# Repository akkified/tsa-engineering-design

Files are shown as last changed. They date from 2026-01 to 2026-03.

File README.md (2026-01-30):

# AI Powered Robotic Arm Lab Assistant

## What It Is

Our team proposes a low-cost, highly accessible lab robotic arm intended for use by students, educators, and small scale labs around the world. This design addresses the lack of access to advanced laboratory automation technologies in underfunded educational and research environments. By implementing additive manufacturing through 3D printing, open source electronics, and wide range mobility, the platform serves as a flexible, modular, and easily accessible laboratory assistant suitable for both instructional and research applications. <br><br>
Because the arm is primarily created using 3D printed components, the overall cost is reduced by approximately 90% compared to a commercially available lab assistant robot. This substantial cost reduction allows for schools, communities, and institutions to create multiple units, therefore increasing accessibility and supporting hands on, scalable learning experiences.<br><br>
All mechanical designs, electronic schematics, and software components have been released as open source materials. Users can independently manufacture the arm, replace individual components as needed, and modify the design files as per their own needs. This open framework also supports a collaborative ecosystem for shared enhancements, including the addition of new grippers, sensors, tools, and automation scripts, allowing for continuous improvements to the design. <br><br>
The robotic arm was designed with a strong emphasis on its mechanical simplicity, flexibility, and ease of construction. A 7 degree of freedom (DOF) configuration was used to create a range of motion beyond that of a human arm, allowing the system to reach complex orientations. All of the components were modeled using computer aided design (CAD), allowing for precision, control over joint geometry, and tolerances. Cycloidal drive mechanisms are implemented into the assemblies to provide high torque and smooth motion while mitigating or significantly reducing backlash, improving the overall positioning accuracy during laboratory tasks. The design of the end effector allows users to replace individual components, attach custom tools, and even integrate new sensors without having to redesign the entire system.<br><br>
	The robotic arm uses an integrated Controller Area Network (CANBUS) communication system to simplify the signal processing and reduce the amount of internal cabling required. In addition to its communication architecture, the system incorporates computer vision using a YOLOv11-based object detection model. Overall, these features improve system efficiency while supporting scalable and adaptable laboratory automation.<br>

## Why We Made This

   We designed this robotic arm to fill a major gap that we observed in educational and laboratory environments. Most advanced tools that assist with automating procedures are extremely expensive and proprietary, which makes  them inaccessible to students and researchers who work in small scale labs who need the most help from this technology. Though the industrial level robotic arms are relatively common in well funded labs and non-educational environments, their high cost and closed ecosystems make the technology significantly less viable to classrooms that could possibly use this as an educational tool, community labs, and underfunded research labs. <br><br>
   In many labs, repetitive tasks like pipetting, sample transfers, positioning instruments, and handling hazardous materials are done manually by the researchers. This seriously limits the possible efficiency of the lab and increases the likelihood of fatigue, human error, and safety hazards. The current industry systems that could automate these tasks cost tens of thousands of dollars and need hgihly specialized maintenance because of their closed off design, which makes them very unrealistic for small scale labs and most schools. <br><br>
   Our main goal with this design was to create a robotic arm that will help significantly reduce the entry barrier to this technology while still remaining functional and precise. By prioritizing the ability to 3D print the majority of the components, open source electronics, and the modular design, we were able to reduce the cost by almost 90% while still creating a highly capable robotic assistant. This arm can be scaled up into a system of communicating assistive devices that can work together. The reduced cost also makes it possible for a high level lab to deploy several of these arms in comparison to a single high cost version. This system will help schools with low funding and small labs create a much more hands on learning environment, run parallel experiments, and scale their automation of tasks. <br><br>
   We chose to make this project fully open source with minimal protections (Reference MIT Licence, txt and CERN Open Hardware Licence Version - Permissive.txt) because we believe that the development  and usage of this technology should not be limited by proprietary constraints like the majority of mainstream robotics technologies. By releasing all of the CAD files, schematics, and software that we have, we hope that the users of this repository will understand the system itself, repair it on their own, and adapt or even improve on our work. We hope that this approach will encourage learning robotics through doing and designing independently. We would love for the global community on GitHub to improve the design over time by creating new end effectors, tools, control strategies, and AI implementations. <br><br>
   Overall, this robotic arm was designed to spread lab automation. It was created to not just be a tool for innovation but also a platform for developing independent work. We hope that our contribution and efforts here will support education, research, and lab automation by making advanced robotic technologies significantly more affordable and customizable to anyone in the community willing to learn and build this technology further.<br>

## CAD Viewer

<script type="module" src="https://unpkg.com/@google/model-viewer/dist/model- viewer.min.js"></script>

<!-- <model-viewer 
  src="https://akkified.github.io/tsa-engineering-design/cad/model.glb" 
  alt="Interactive CAD model" 
  auto-rotate 
  camera-controls 
  ar 
  style="width: 100%; height: 400px;">
</model-viewer> -->

## Images

### 3D CAD Model
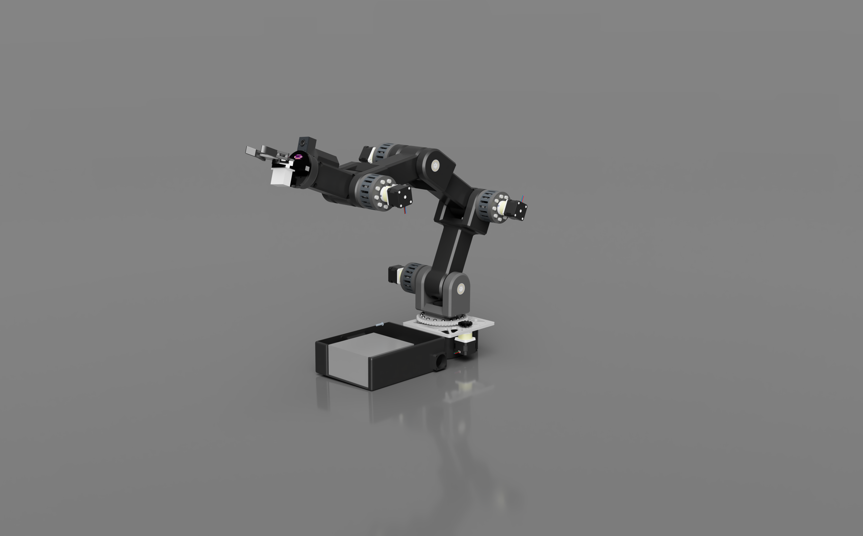
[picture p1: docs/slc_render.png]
Render

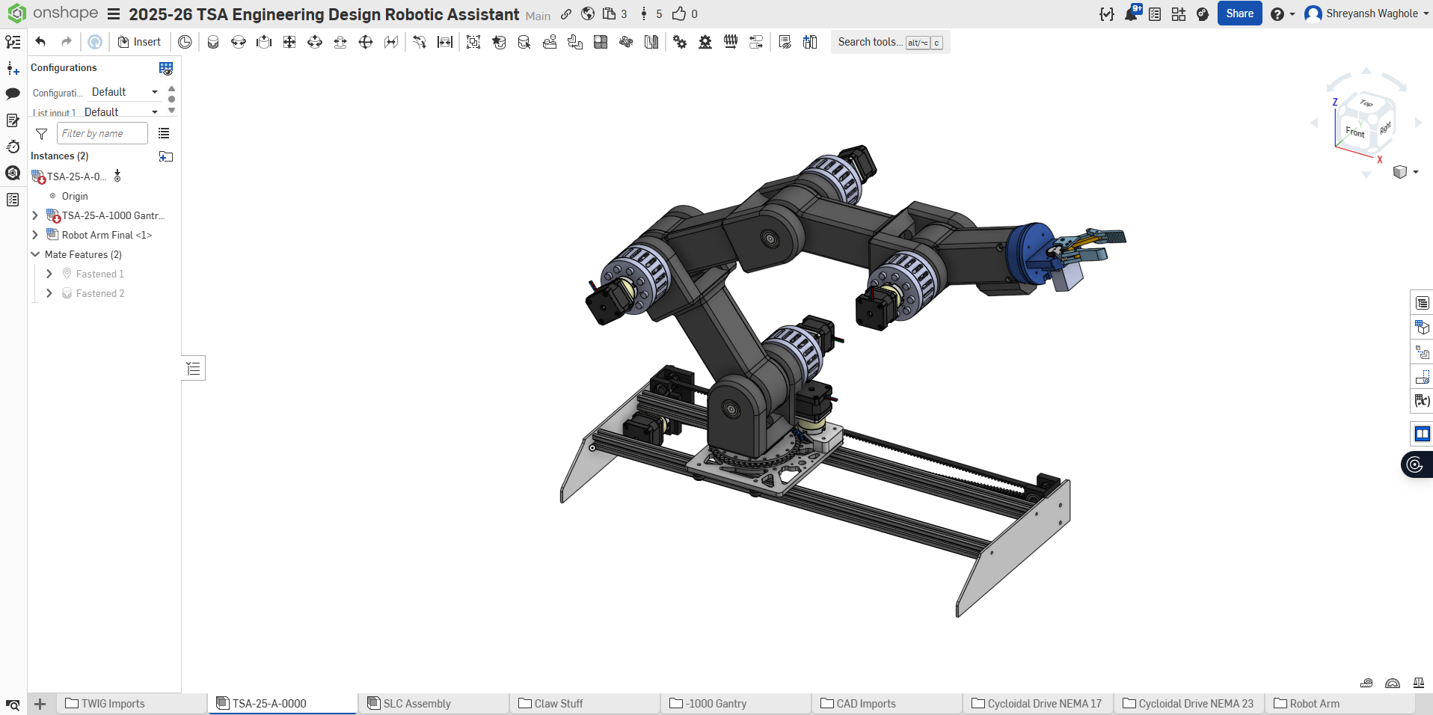
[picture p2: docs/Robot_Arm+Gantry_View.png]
Robot Arm Gantry View

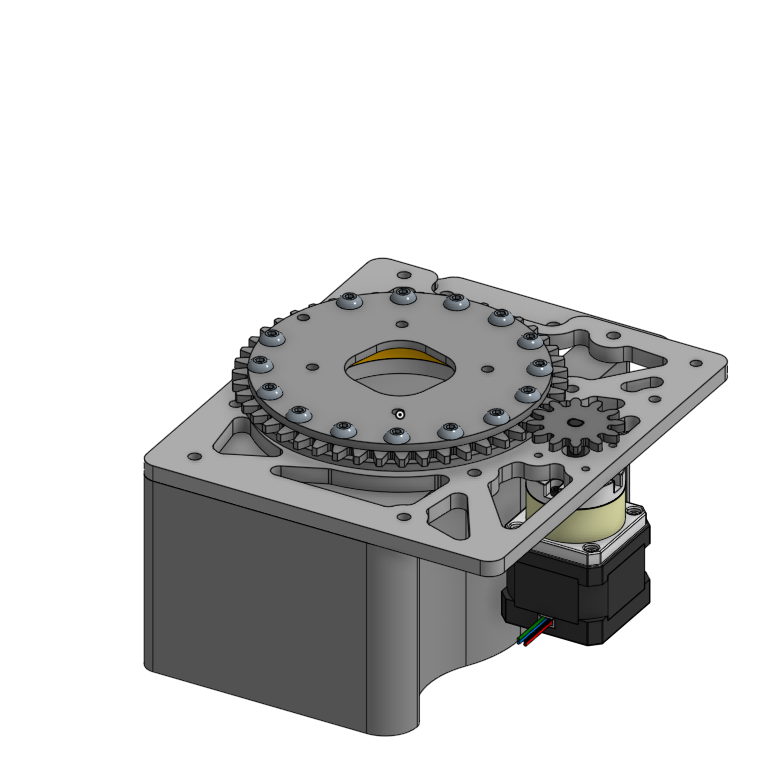
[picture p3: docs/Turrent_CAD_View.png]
Turret CAD View

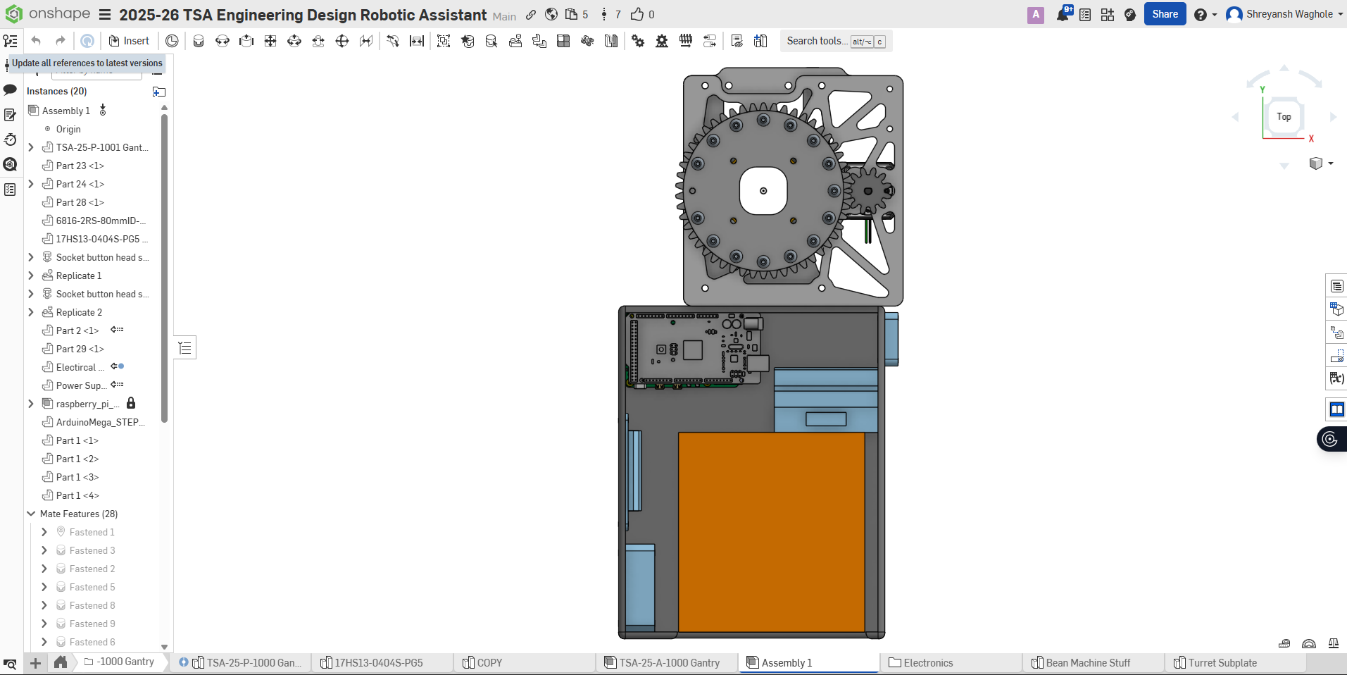
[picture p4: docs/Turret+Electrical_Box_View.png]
Turret Electrical Box View


### Wiring Diagram
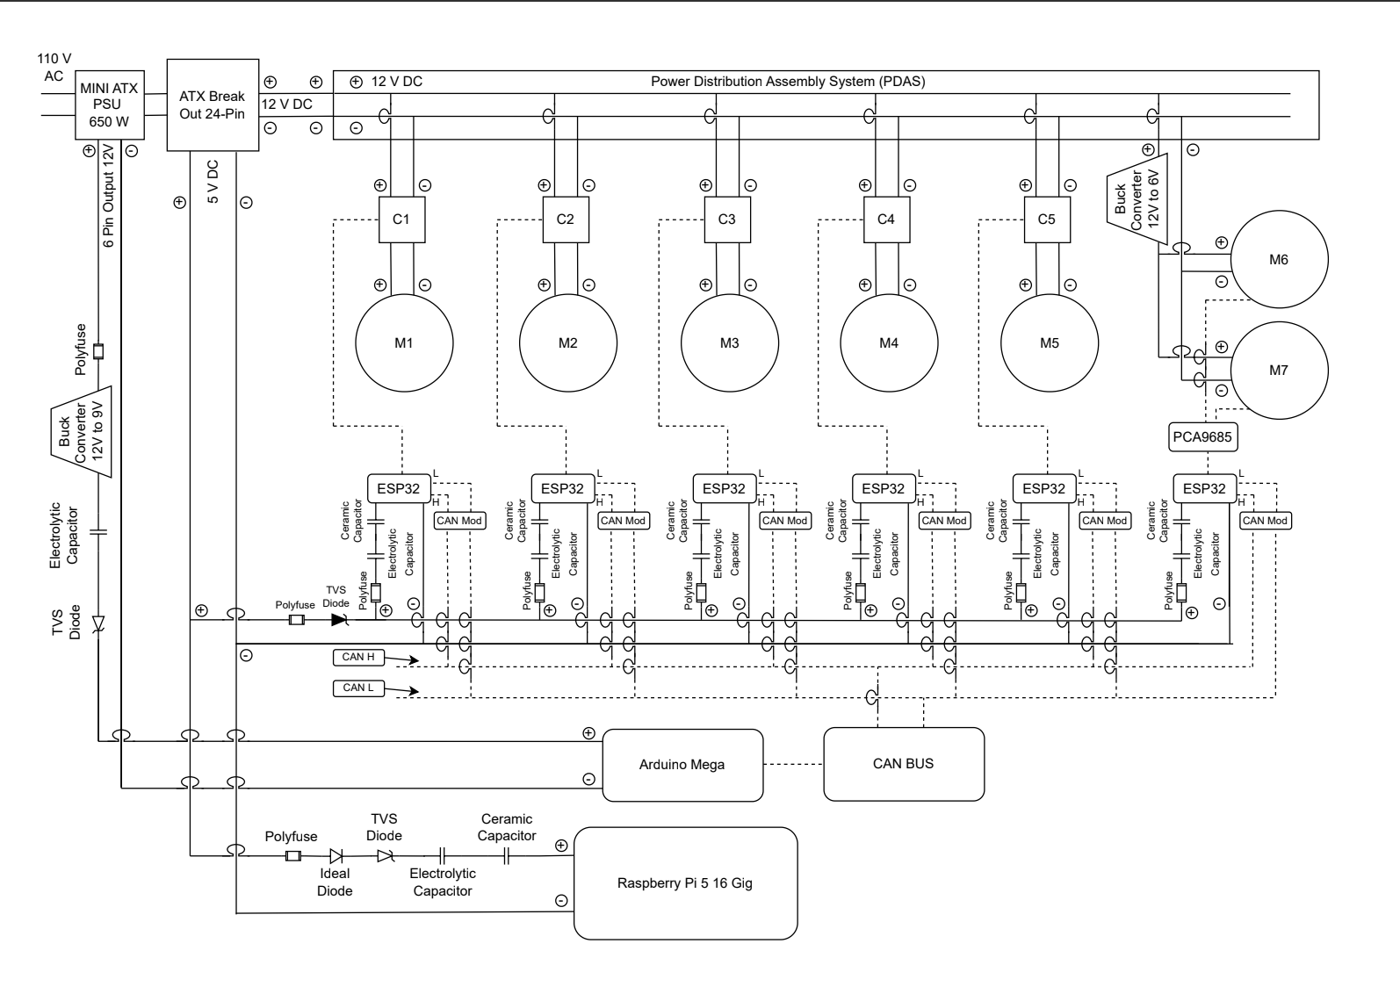
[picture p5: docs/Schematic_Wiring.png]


### AI Performance (Vision)
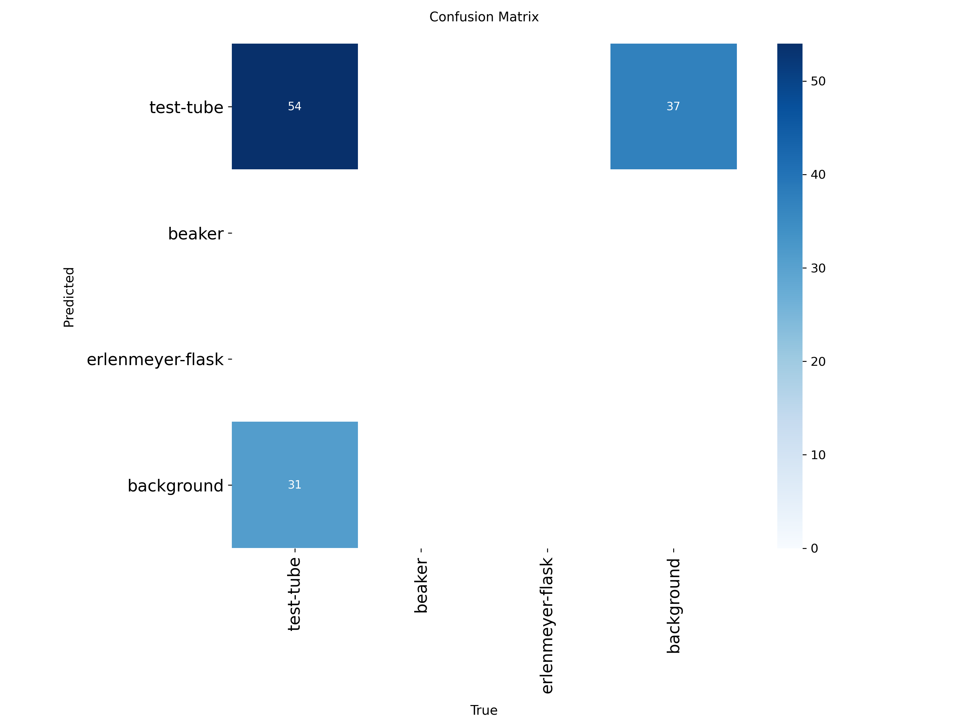
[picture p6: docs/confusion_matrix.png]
Confusion Matrix


### Cycloidal
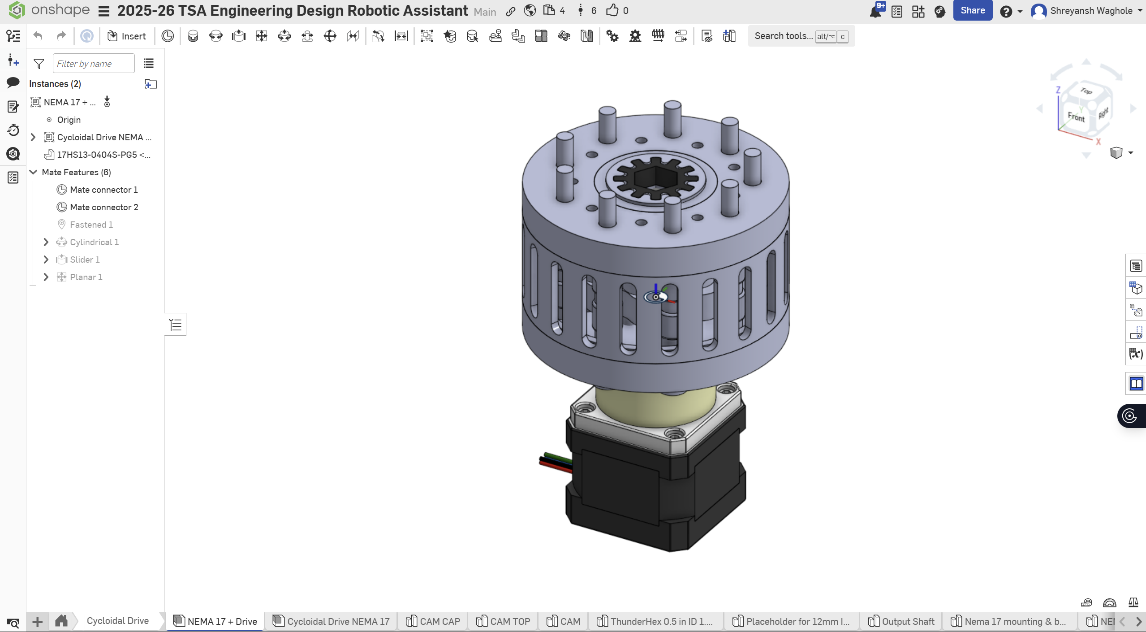
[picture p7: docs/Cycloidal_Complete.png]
Complete Cycloidal

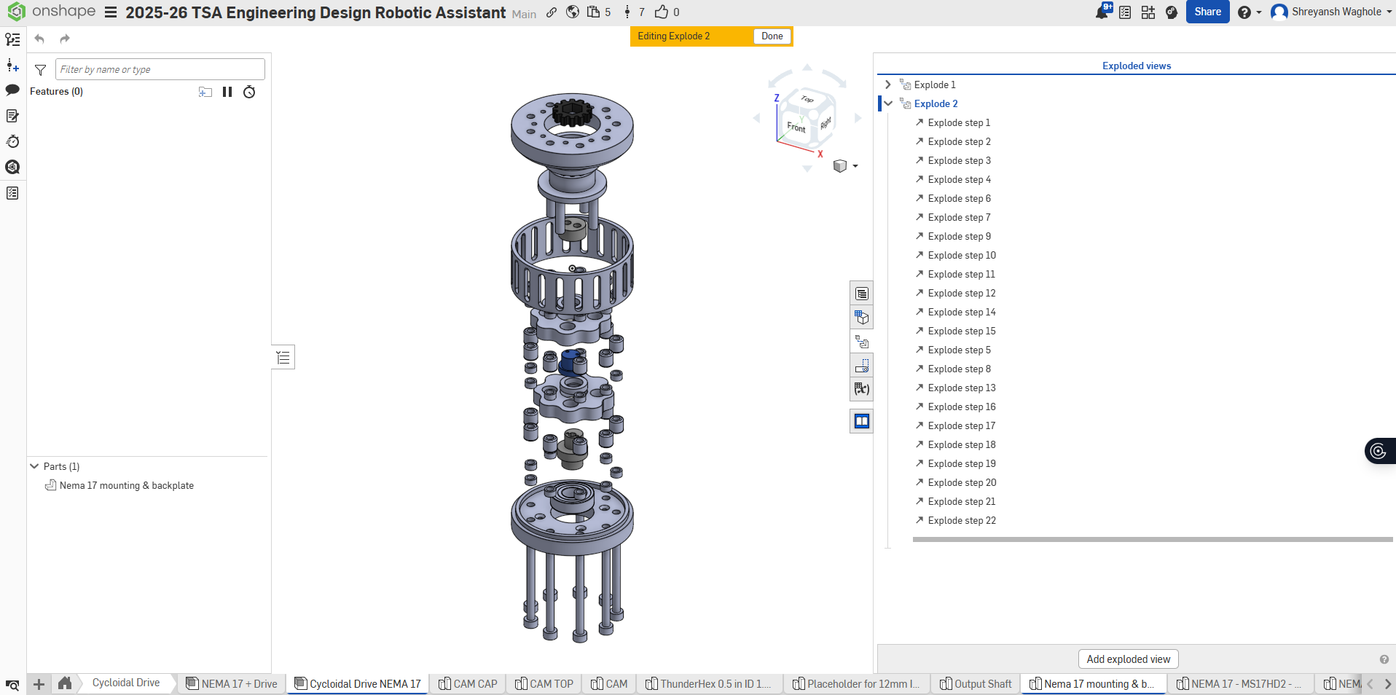
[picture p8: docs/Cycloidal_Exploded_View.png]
Exploded Cycloidal View

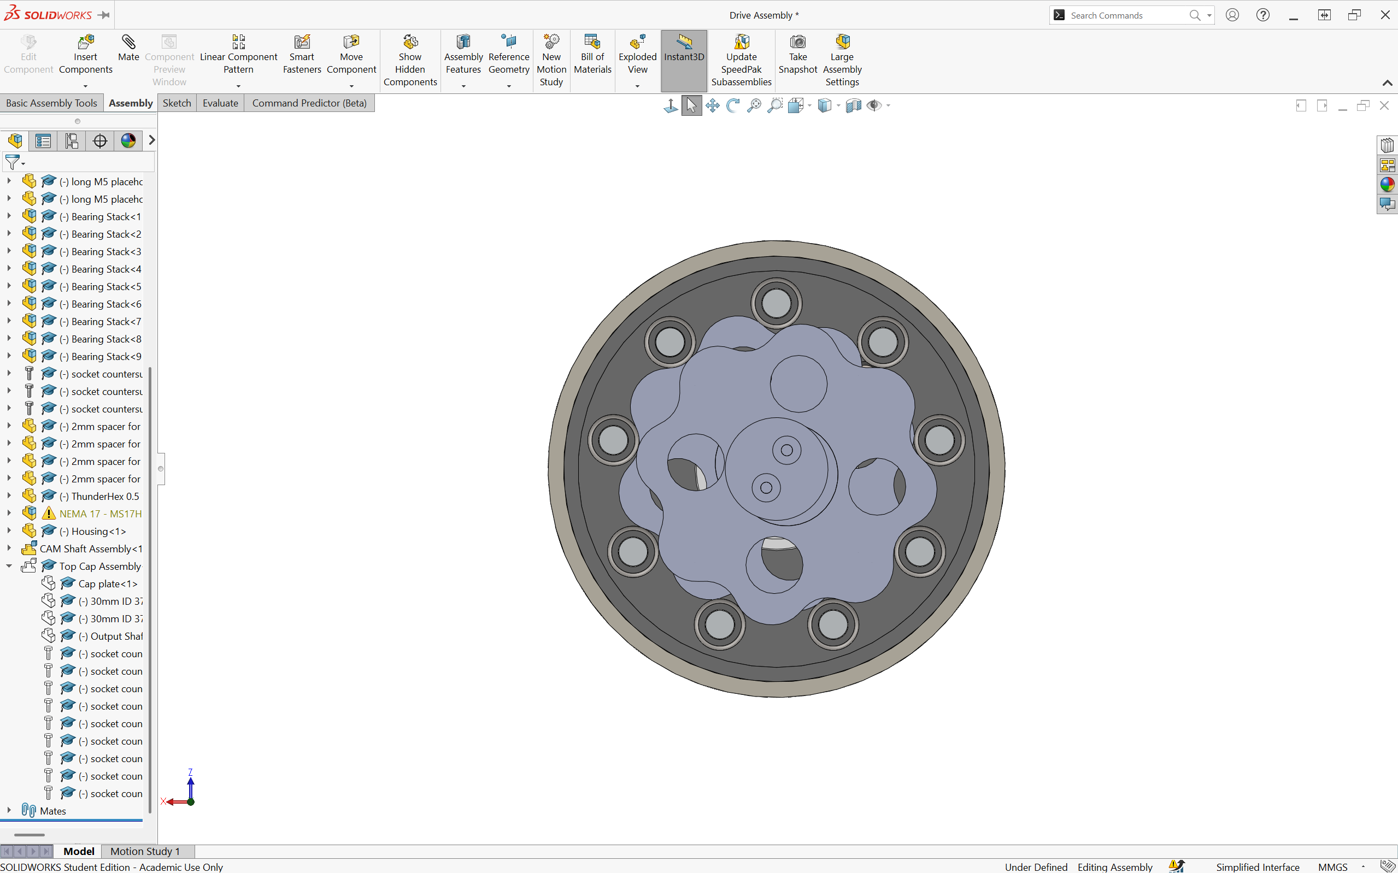
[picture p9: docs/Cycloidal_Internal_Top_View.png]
Cycloidal Internal Top View

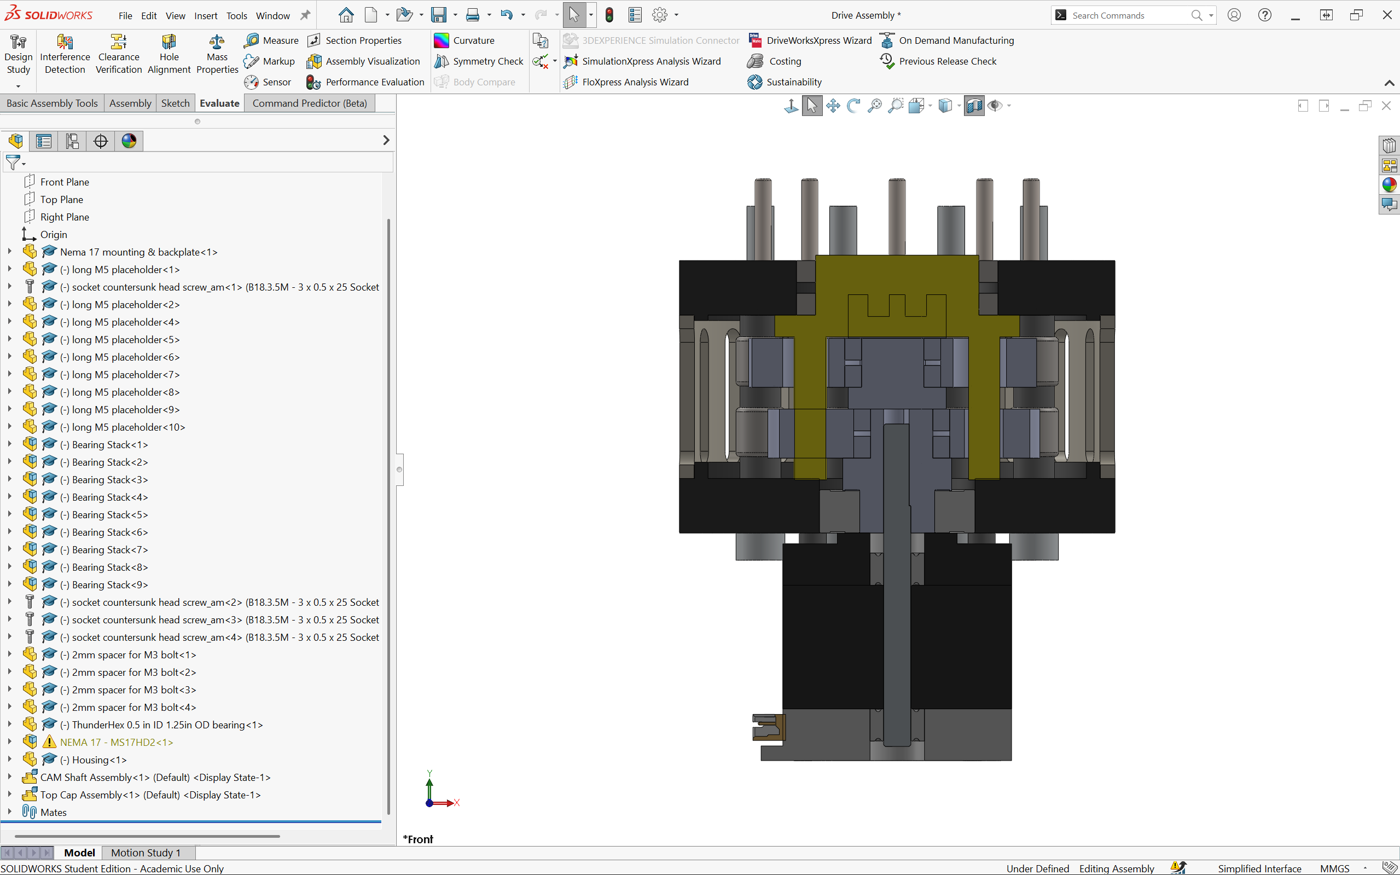
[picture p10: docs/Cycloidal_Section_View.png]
Cycloidal Section View

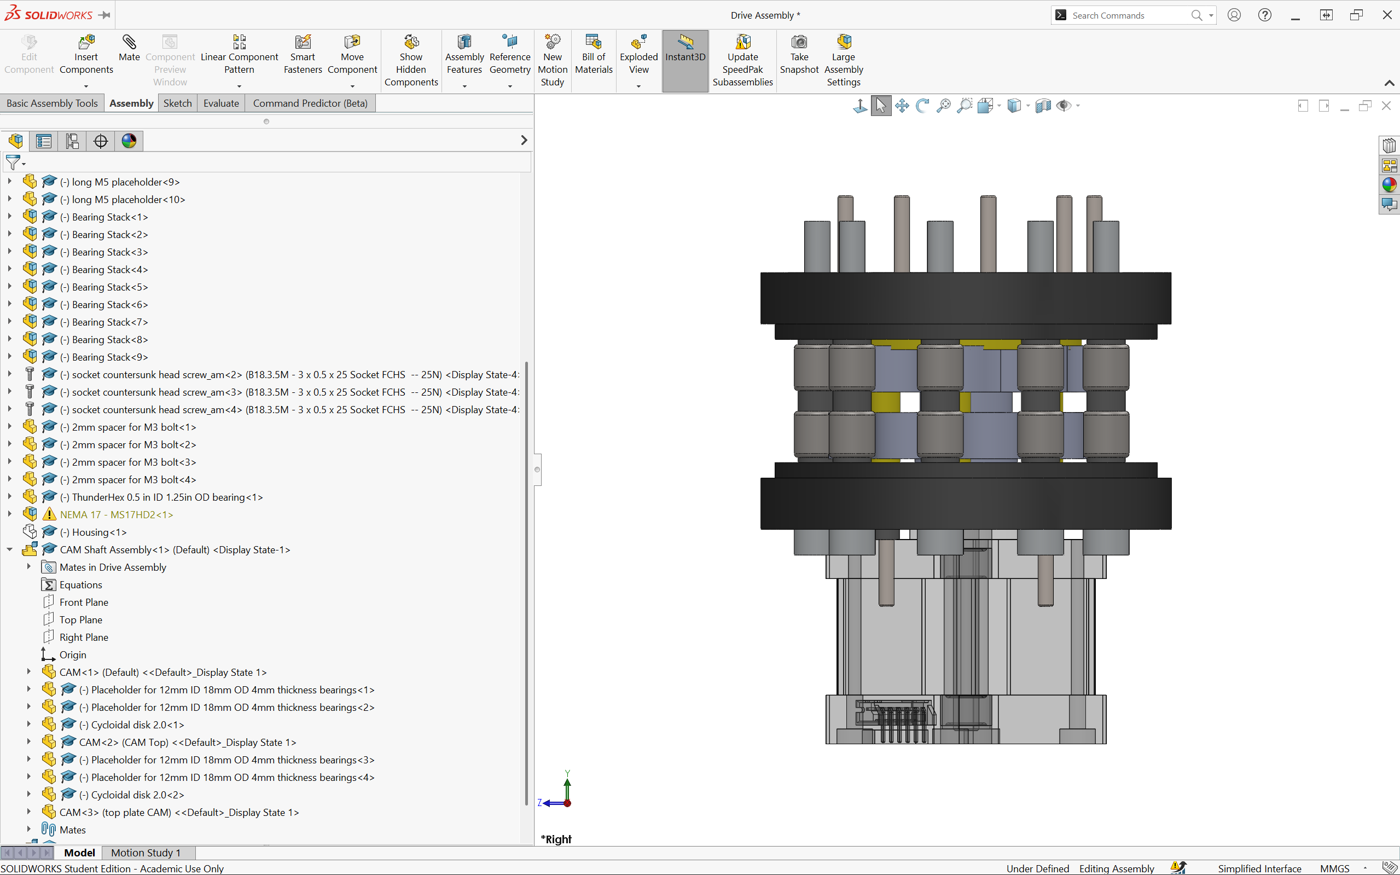
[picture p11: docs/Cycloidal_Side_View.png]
Cycloidal Side View

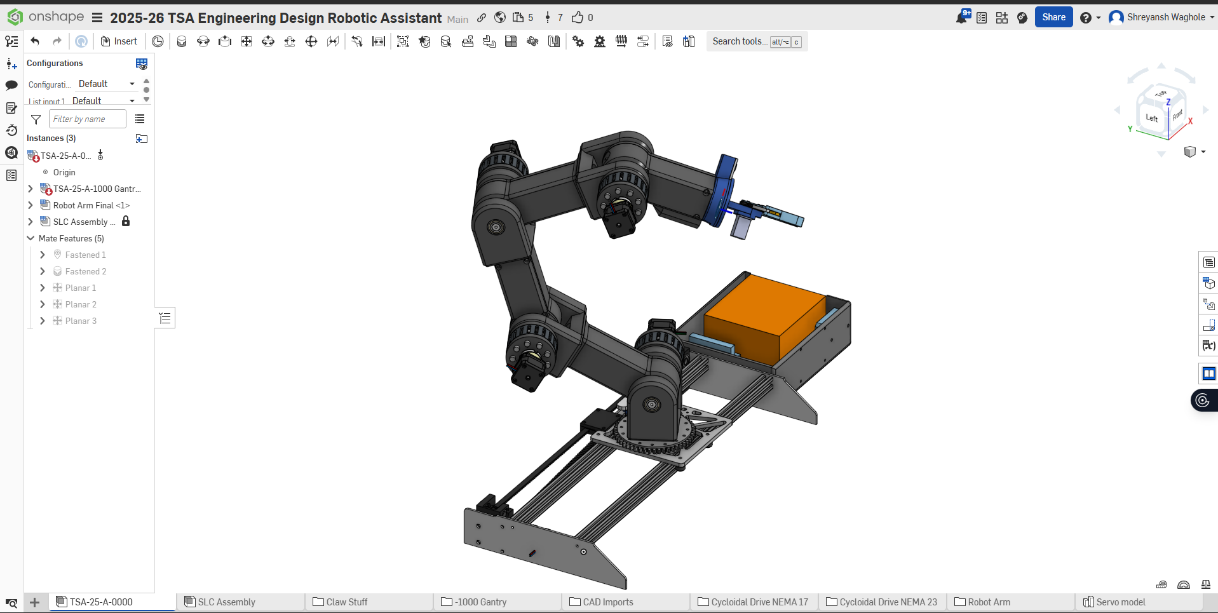
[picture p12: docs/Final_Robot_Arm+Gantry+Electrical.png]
Final Robot Arm Gantry Electrical

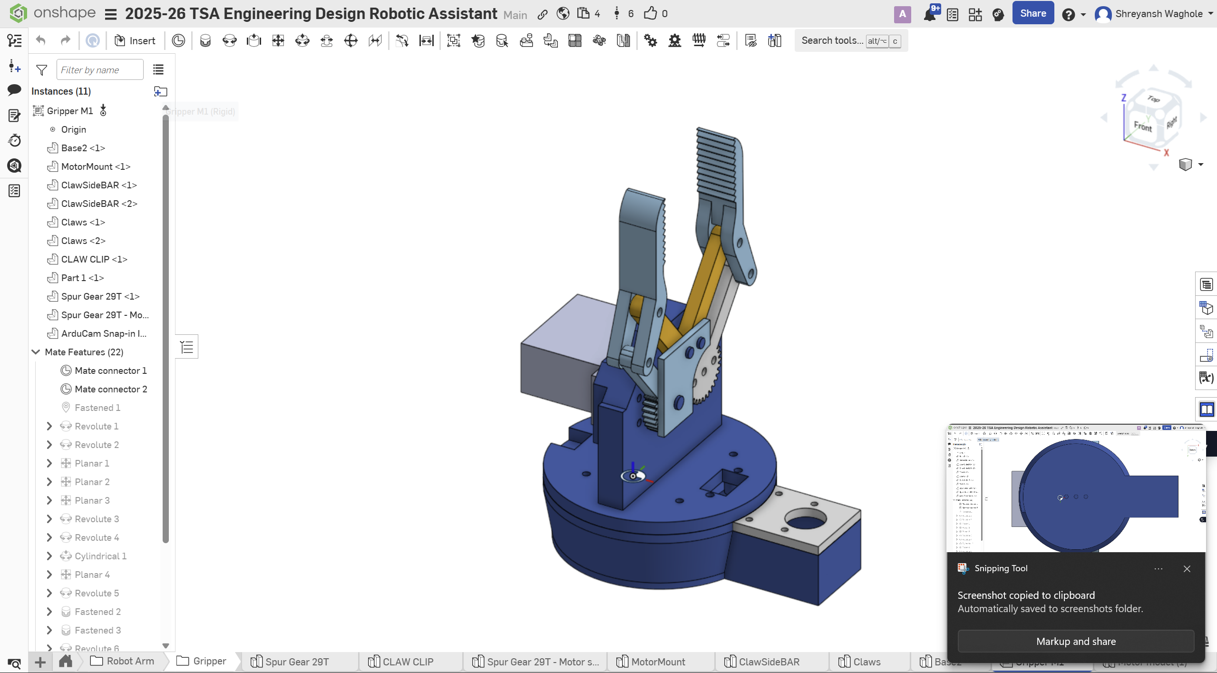
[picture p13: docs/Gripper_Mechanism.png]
Gripper Mechanism


### Gripper
Gripper Mechanism

## Bill of Materials

| Item | Description | Quantity | Link |
| :--- | :--- | :--- | :--- |
| TSA-26-P-1001 | Gantry Cart Plate | 1 | [Link](https://cad.onshape.com/documents/f3370c452f54d75f3c4d6ebc/w/d75891e42061a97cb25fbb77/e/19dbb1aef07b81d3e2e158b9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) |
| TSA-26-P-1002 | Gantry Side Plate | 1 | [Link](https://cad.onshape.com/documents/f3370c452f54d75f3c4d6ebc/w/d75891e42061a97cb25fbb77/e/19dbb1aef07b81d3e2e158b9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) |
| TSA-26-P-1003 | Gantry Side Plate 2  | 1 | [Link](https://cad.onshape.com/documents/f3370c452f54d75f3c4d6ebc/w/d75891e42061a97cb25fbb77/e/19dbb1aef07b81d3e2e158b9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) |
| TSA-26-P-1004 | Bottom Belt Clamp | 1 | [Link](https://cad.onshape.com/documents/f3370c452f54d75f3c4d6ebc/w/d75891e42061a97cb25fbb77/e/19dbb1aef07b81d3e2e158b9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) |
| TSA-26-P-1005 | Top Gantry Clamp | 1 | [Link](https://cad.onshape.com/documents/f3370c452f54d75f3c4d6ebc/w/d75891e42061a97cb25fbb77/e/19dbb1aef07b81d3e2e158b9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) |
| TSA-26-P-1006 | Gantry Drive Block | 1 | [Link](https://cad.onshape.com/documents/f3370c452f54d75f3c4d6ebc/w/d75891e42061a97cb25fbb77/e/19dbb1aef07b81d3e2e158b9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) |
| TSA-26-P-1007 | Idler Drive Block | 1 | [Link](https://cad.onshape.com/documents/f3370c452f54d75f3c4d6ebc/w/d75891e42061a97cb25fbb77/e/19dbb1aef07b81d3e2e158b9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) |
| TSA-26-P-1008 | Stepper Drive Shaft | 1 | [Link](https://cad.onshape.com/documents/f3370c452f54d75f3c4d6ebc/w/d75891e42061a97cb25fbb77/e/19dbb1aef07b81d3e2e158b9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) |
| TSA-26-P-1009 | Sideplate Support Block | 1 | [Link](https://cad.onshape.com/documents/f3370c452f54d75f3c4d6ebc/w/d75891e42061a97cb25fbb77/e/19dbb1aef07b81d3e2e158b9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) |
| TSA-26-P-1010 | Idler Pulley Shaft | 1 | [Link](https://cad.onshape.com/documents/f3370c452f54d75f3c4d6ebc/w/d75891e42061a97cb25fbb77/e/19dbb1aef07b81d3e2e158b9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) |
| TSA-26-P-1011 | Gantry Motor Plate | 1 | [Link](https://cad.onshape.com/documents/f3370c452f54d75f3c4d6ebc/w/d75891e42061a97cb25fbb77/e/19dbb1aef07b81d3e2e158b9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) |
| TSA-26-P-1012 | Top Idler Shaft | 1 | [Link](https://cad.onshape.com/documents/f3370c452f54d75f3c4d6ebc/w/d75891e42061a97cb25fbb77/e/19dbb1aef07b81d3e2e158b9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) |
| TSA-26-P-1013 | Bearing Clamp Block | 1 | [Link](https://cad.onshape.com/documents/f3370c452f54d75f3c4d6ebc/w/d75891e42061a97cb25fbb77/e/19dbb1aef07b81d3e2e158b9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) |
| TSA-26-P-1014 | Turret Mega Gear | 1 | [Link](https://cad.onshape.com/documents/f3370c452f54d75f3c4d6ebc/w/d75891e42061a97cb25fbb77/e/19dbb1aef07b81d3e2e158b9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) |
| TSA-26-P-1015 | Turret Top Face Plate | 1 | [Link](https://cad.onshape.com/documents/f3370c452f54d75f3c4d6ebc/w/d75891e42061a97cb25fbb77/e/19dbb1aef07b81d3e2e158b9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) |
| TSA-26-P-1016 | Turret Stepper Spur Gear | 1 | [Link](https://cad.onshape.com/documents/f3370c452f54d75f3c4d6ebc/w/d75891e42061a97cb25fbb77/e/19dbb1aef07b81d3e2e158b9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) |
| TSA-26-P-1017 | 16T HTD Pulley | 1 | [Link](https://cad.onshape.com/documents/f3370c452f54d75f3c4d6ebc/w/d75891e42061a97cb25fbb77/e/19dbb1aef07b81d3e2e158b9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) |
| TSA-26-P-1018 | 12T HTD Pulley | 2 | [Link](https://cad.onshape.com/documents/f3370c452f54d75f3c4d6ebc/w/d75891e42061a97cb25fbb77/e/19dbb1aef07b81d3e2e158b9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) |
| V-Slot 20x20x500 Linear Rail | V-Slot 20x20x500 Linear Rail | 2 | [Link](amazon.com/Seekliny-Aluminum-Extrusion-V-Slotted-Accessories/dp/B0DY7HTF64/ref=sr_1_4?crid=2XZJS4FL1F96O&dib=eyJ2IjoiMSJ9.Ac3P7DHsJClEaBba3uS4z0TF3Njk0aX5qsHx9eAZKVYe0E3uR7Y7049Nr2TUYWWROzSkqay74nQcwlPM9SRy9RS-nazLpZmBX2XZMilzl5ezOM1P1l5QNxDUTyvYWSvyw5T_pdYnNHySHUVVmbdfHIc-dCnuMA5W4nbLpQkIYnH0eTH-YCFQywWMR9SoS_m9iueO_Zvjn_C2PwxK7_1OM0MnLjR6LqhkJFpIY-68bDU.rM0o6ytShiE_gbBSqp4TNnfBsuJUcUOJwdTYlyX93-0&dib_tag=se&keywords=V-Slot+20x20x500+Linear+Rail&qid=1767666841&sprefix=v-slot+20x20x500+linear+rail%2Caps%2C157&sr=8-4) |
| WCP-0643 | 250T 5M 9mm Wide Belt | 1 | [Link](https://wcproducts.com/products/htd-timing-belts-9mm-width) |
| 17HS13-0404S-PG5 | Nema 17 Stepper Motor Bipolar L=34mm w/ Gear Ratio 14:1 Planetary Gearbox | 2 | [Link](https://www.amazon.com/gp/product/B00QA8XUGC/ref=ox_sc_act_title_10?smid=AWQBCGWISS7BL&psc=1) |
| 6816-2RS-80mm | Ball Bearing 80x100x10mm Sealed | 1 | [Link](https://www.amazon.com/gp/product/B07RQ4RXDR/ref=ox_sc_act_title_4?smid=A1THAZDOWP300U&th=1) |
| TSA-26-P-2001 | Cam Shaft Cap | 4 | [Link](https://cad.onshape.com/documents/f3370c452f54d75f3c4d6ebc/w/d75891e42061a97cb25fbb77/e/19dbb1aef07b81d3e2e158b9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) |
| TSA-26-P-2002 | Cam Shaft Upper | 4 | [Link](https://cad.onshape.com/documents/f3370c452f54d75f3c4d6ebc/w/d75891e42061a97cb25fbb77/e/19dbb1aef07b81d3e2e158b9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) |
| TSA-26-P-2003 | Cam Shaft Lower | 4 | [Link](https://cad.onshape.com/documents/f3370c452f54d75f3c4d6ebc/w/d75891e42061a97cb25fbb77/e/19dbb1aef07b81d3e2e158b9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) |
| TSA-26-P-2004 | ThunderHex 0.5 in ID 1.25in OD bearing | 4 | [Link](https://wcproducts.com/products/wcp-0778?variant=35666611994784) |
| TSA-26-P-2005 | 12mm ID 18mm OD 4mm thickness bearings | 16 | [Link](https://www.amazon.com/gp/product/B082PQ8DC2/ref=ox_sc_act_title_28?smid=A30WUG2ZDGM0XM&psc=1) |
| TSA-26-P-2006 | Output Shaft | 4 | [Link](https://cad.onshape.com/documents/f3370c452f54d75f3c4d6ebc/w/d75891e42061a97cb25fbb77/e/19dbb1aef07b81d3e2e158b9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) |
| TSA-26-P-2007 | Backplate | 4 | [Link](https://cad.onshape.com/documents/f3370c452f54d75f3c4d6ebc/w/d75891e42061a97cb25fbb77/e/19dbb1aef07b81d3e2e158b9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) |
| TSA-26-P-2008 | M5 * 60mm Hex Socket Head Cap Screw | 36 | [Link](https://www.aliexpress.us/item/3256805692722422.html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) |
| TSA-26-P-2009 | Housing | 4 | [Link](https://cad.onshape.com/documents/f3370c452f54d75f3c4d6ebc/w/d75891e42061a97cb25fbb77/e/19dbb1aef07b81d3e2e158b9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) |
| TSA-26-P-2010 | Cycloidal Disk | 8 | [Link](https://cad.onshape.com/documents/f3370c452f54d75f3c4d6ebc/w/d75891e42061a97cb25fbb77/e/19dbb1aef07b81d3e2e158b9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) |
| TSA-26-P-2011 | 5mm ID 9mm OD needle roller bearings | 72 | [Link](https://www.aliexpress.us/item/3256804660266970.html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) |
| TSA-26-P-2012 | Cap Plate | 4 | [Link](https://cad.onshape.com/documents/f3370c452f54d75f3c4d6ebc/w/d75891e42061a97cb25fbb77/e/19dbb1aef07b81d3e2e158b9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) |
| TSA-26-P-2013 | Ball Bearings Z2 30mm x 37mm x 4mm | 8 | [Link](https://www.aliexpress.us/item/2255800723290638.html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) |
| TSA-26-P-2014 | 4mm Spacer for M5 | 108 | [Link](https://cad.onshape.com/documents/f3370c452f54d75f3c4d6ebc/w/d75891e42061a97cb25fbb77/e/19dbb1aef07b81d3e2e158b9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) |
| TSA-26-P-2015 | 3D-Print Adapter (1/2" Hex Bore, Thrifty Profile) | 4 | [Link](https://wcproducts.com/products/wcp-1121?variant=44283598045396) |
| TSA-26-P-2016 | Nema 17 Stepper Motor Bipolar L=34mm w/ Gear Ratio 14:1 Planetary Gearbox | 4 | [Link](https://www.amazon.com/gp/product/B00QA8XUGC/ref=ox_sc_act_title_10?smid=AWQBCGWISS7BL&psc=1) |
| TSA-26-P-3001 | Base Arm Segment | 3 | [Link](https://cad.onshape.com/documents/f3370c452f54d75f3c4d6ebc/w/d75891e42061a97cb25fbb77/e/19dbb1aef07b81d3e2e158b9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) |
| TSA-26-P-3002 | Arm segment Cap Plate | 4 | [Link](https://cad.onshape.com/documents/f3370c452f54d75f3c4d6ebc/w/d75891e42061a97cb25fbb77/e/19dbb1aef07b81d3e2e158b9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) |
| TSA-26-P-3003 | Gripper Mount Arm Segment | 1 | [Link](https://cad.onshape.com/documents/f3370c452f54d75f3c4d6ebc/w/d75891e42061a97cb25fbb77/e/19dbb1aef07b81d3e2e158b9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) |
| TSA-26-P-3004 | Turret Mounted Arm Segment | 1 | [Link](https://cad.onshape.com/documents/f3370c452f54d75f3c4d6ebc/w/d75891e42061a97cb25fbb77/e/19dbb1aef07b81d3e2e158b9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) |
| TSA-26-P-4001 | Spur Gear 29T Non-Powered | 1 | [Link](https://cad.onshape.com/documents/f3370c452f54d75f3c4d6ebc/w/d75891e42061a97cb25fbb77/e/19dbb1aef07b81d3e2e158b9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) |
| TSA-26-P-4002 | Spur Gear 29T - Motor Side | 1 | [Link](https://cad.onshape.com/documents/f3370c452f54d75f3c4d6ebc/w/d75891e42061a97cb25fbb77/e/19dbb1aef07b81d3e2e158b9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) |
| TSA-26-P-4003 | Claw Cap Plate | 1 | [Link](https://cad.onshape.com/documents/f3370c452f54d75f3c4d6ebc/w/d75891e42061a97cb25fbb77/e/19dbb1aef07b81d3e2e158b9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) |
| TSA-26-P-4004 | Servo Mount | 1 | [Link](https://cad.onshape.com/documents/f3370c452f54d75f3c4d6ebc/w/d75891e42061a97cb25fbb77/e/19dbb1aef07b81d3e2e158b9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) |
| TSA-26-P-4005 | Claw Secondary Bar | 2 | [Link](https://cad.onshape.com/documents/f3370c452f54d75f3c4d6ebc/w/d75891e42061a97cb25fbb77/e/19dbb1aef07b81d3e2e158b9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) |
| TSA-26-P-4006 | Claw | 2 | [Link](https://cad.onshape.com/documents/f3370c452f54d75f3c4d6ebc/w/d75891e42061a97cb25fbb77/e/19dbb1aef07b81d3e2e158b9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) |
| TSA-26-P-4007 | Base | 1 | [Link](https://cad.onshape.com/documents/f3370c452f54d75f3c4d6ebc/w/d75891e42061a97cb25fbb77/e/19dbb1aef07b81d3e2e158b9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) |
| TSA-26-P-4008 | ArduCAM Snap-In Insert | 1 | [Link](https://cad.onshape.com/documents/f3370c452f54d75f3c4d6ebc/w/d75891e42061a97cb25fbb77/e/19dbb1aef07b81d3e2e158b9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) |
| TSA-26-P-4009 | Distance Sensor - VL53L0X v8 | 1 | [Link](https://www.aliexpress.us/item/3256807932833735.html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) |
| TSA-26-P-4010 | ArduCAM - IMX477 | 1 | [Link](amazon.com/gp/product/B09VSVB4DT/ref=ox_sc_act_title_6?smid=A2IAB2RW3LLT8D&psc=1) |
| TSA-26-P-4011 | Servo - DSSERVO 30KG | 2 | [Link](https://www.aliexpress.us/item/3256807345822029.html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) |

*update_bom.py is a script

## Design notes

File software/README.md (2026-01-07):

# AI & Software

This folder contains the software and logic behind the systems!

## AI Performance 

We trained a custom YOLO model to identify 3 specific classes of objects. Below are our results:

### 1. Confusion Matrix

This chart shows where the model is strongest.

Confusion Matrix

### 2. Results

These graphs show progress.

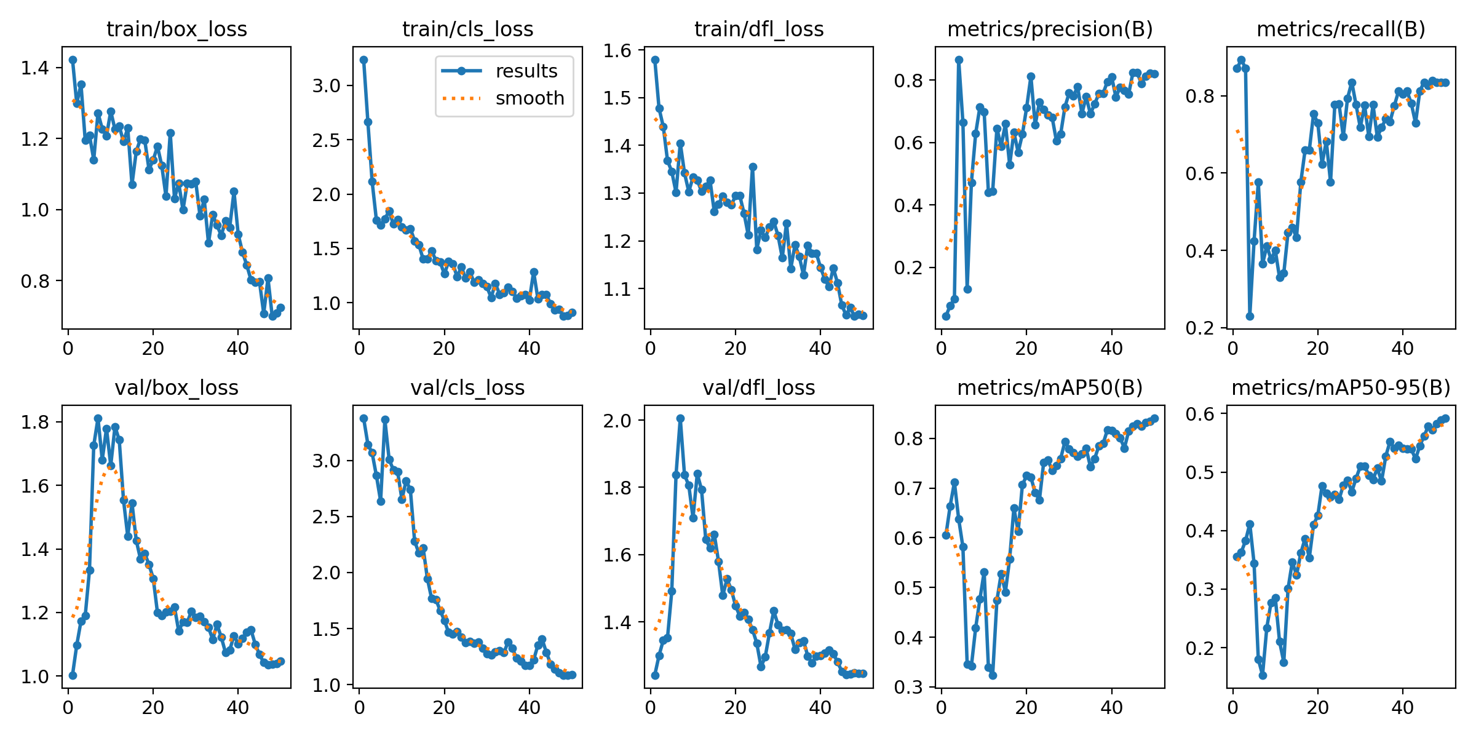
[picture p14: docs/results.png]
Performance


### 3. Samples

Here is what the AI sees:

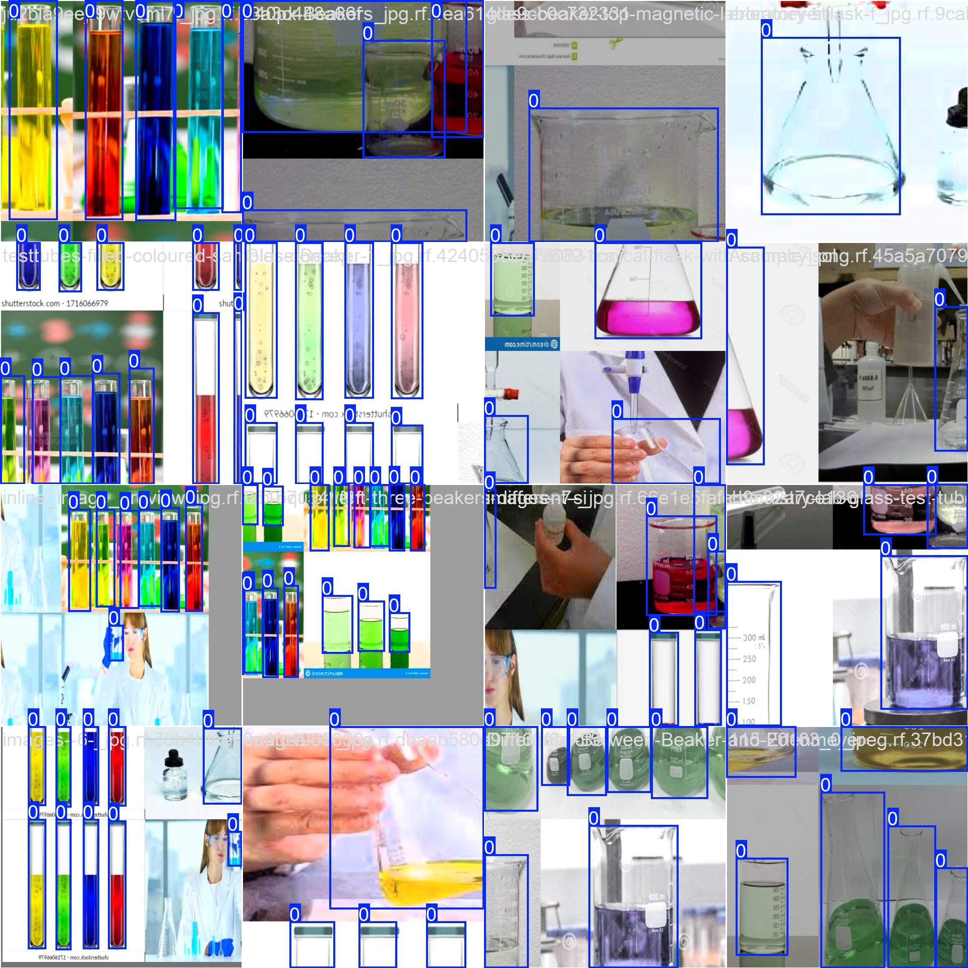
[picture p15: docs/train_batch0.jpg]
Batch Sample


## Folders

### [/rpi](./rpi)
Runs on RPI 5
* `robot_brain.py`: Main Python controller. Hosts a Flask web server
* `lab_items_v1.pt`: Custom-trained weights
* `train_yolo.py`: Used to train the model on my custom dataset.

### [/arduino](./arduino)
Runs on the Arduino Mega
* `motor_control.ino`: Firmware that uses the `AccelStepper` library to move 5 motors at once without freezing, motor ports will be finalized after build

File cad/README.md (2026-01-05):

# CAD

This folder contains the CAD!

[Link To Onshape!](https://cad.onshape.com/documents/f3370c452f54d75f3c4d6ebc/w/d75891e42061a97cb25fbb77/e/15b8c7536231aa31462fe383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)

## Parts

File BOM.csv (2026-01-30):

Item | Description | Quantity | Link
TSA-26-P-1001 | Gantry Cart Plate | 1 | https://cad.onshape.com/documents/f3370c452f54d75f3c4d6ebc/w/d75891e42061a97cb25fbb77/e/19dbb1aef07b81d3e2e158b9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
TSA-26-P-1002 | Gantry Side Plate | 1 | https://cad.onshape.com/documents/f3370c452f54d75f3c4d6ebc/w/d75891e42061a97cb25fbb77/e/19dbb1aef07b81d3e2e158b9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
TSA-26-P-1003 | Gantry Side Plate 2 | 1 | https://cad.onshape.com/documents/f3370c452f54d75f3c4d6ebc/w/d75891e42061a97cb25fbb77/e/19dbb1aef07b81d3e2e158b9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
TSA-26-P-1004 | Bottom Belt Clamp | 1 | https://cad.onshape.com/documents/f3370c452f54d75f3c4d6ebc/w/d75891e42061a97cb25fbb77/e/19dbb1aef07b81d3e2e158b9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
TSA-26-P-1005 | Top Gantry Clamp | 1 | https://cad.onshape.com/documents/f3370c452f54d75f3c4d6ebc/w/d75891e42061a97cb25fbb77/e/19dbb1aef07b81d3e2e158b9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
TSA-26-P-1006 | Gantry Drive Block | 1 | https://cad.onshape.com/documents/f3370c452f54d75f3c4d6ebc/w/d75891e42061a97cb25fbb77/e/19dbb1aef07b81d3e2e158b9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
TSA-26-P-1007 | Idler Drive Block | 1 | https://cad.onshape.com/documents/f3370c452f54d75f3c4d6ebc/w/d75891e42061a97cb25fbb77/e/19dbb1aef07b81d3e2e158b9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
TSA-26-P-1008 | Stepper Drive Shaft | 1 | https://cad.onshape.com/documents/f3370c452f54d75f3c4d6ebc/w/d75891e42061a97cb25fbb77/e/19dbb1aef07b81d3e2e158b9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
TSA-26-P-1009 | Sideplate Support Block | 1 | https://cad.onshape.com/documents/f3370c452f54d75f3c4d6ebc/w/d75891e42061a97cb25fbb77/e/19dbb1aef07b81d3e2e158b9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
TSA-26-P-1010 | Idler Pulley Shaft | 1 | https://cad.onshape.com/documents/f3370c452f54d75f3c4d6ebc/w/d75891e42061a97cb25fbb77/e/19dbb1aef07b81d3e2e158b9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
TSA-26-P-1011 | Gantry Motor Plate | 1 | https://cad.onshape.com/documents/f3370c452f54d75f3c4d6ebc/w/d75891e42061a97cb25fbb77/e/19dbb1aef07b81d3e2e158b9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
TSA-26-P-1012 | Top Idler Shaft | 1 | https://cad.onshape.com/documents/f3370c452f54d75f3c4d6ebc/w/d75891e42061a97cb25fbb77/e/19dbb1aef07b81d3e2e158b9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
TSA-26-P-1013 | Bearing Clamp Block | 1 | https://cad.onshape.com/documents/f3370c452f54d75f3c4d6ebc/w/d75891e42061a97cb25fbb77/e/19dbb1aef07b81d3e2e158b9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
TSA-26-P-1014 | Turret Mega Gear | 1 | https://cad.onshape.com/documents/f3370c452f54d75f3c4d6ebc/w/d75891e42061a97cb25fbb77/e/19dbb1aef07b81d3e2e158b9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
TSA-26-P-1015 | Turret Top Face Plate | 1 | https://cad.onshape.com/documents/f3370c452f54d75f3c4d6ebc/w/d75891e42061a97cb25fbb77/e/19dbb1aef07b81d3e2e158b9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
TSA-26-P-1016 | Turret Stepper Spur Gear | 1 | https://cad.onshape.com/documents/f3370c452f54d75f3c4d6ebc/w/d75891e42061a97cb25fbb77/e/19dbb1aef07b81d3e2e158b9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
TSA-26-P-1017 | 16T HTD Pulley | 1 | https://cad.onshape.com/documents/f3370c452f54d75f3c4d6ebc/w/d75891e42061a97cb25fbb77/e/19dbb1aef07b81d3e2e158b9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
TSA-26-P-1018 | 12T HTD Pulley | 2 | https://cad.onshape.com/documents/f3370c452f54d75f3c4d6ebc/w/d75891e42061a97cb25fbb77/e/19dbb1aef07b81d3e2e158b9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
V-Slot 20x20x500 Linear Rail | V-Slot 20x20x500 Linear Rail | 2 | amazon.com/Seekliny-Aluminum-Extrusion-V-Slotted-Accessories/dp/B0DY7HTF64/ref=sr_1_4?crid=2XZJS4FL1F96O&dib=eyJ2IjoiMSJ9.Ac3P7DHsJClEaBba3uS4z0TF3Njk0aX5qsHx9eAZKVYe0E3uR7Y7049Nr2TUYWWROzSkqay74nQcwlPM9SRy9RS-nazLpZmBX2XZMilzl5ezOM1P1l5QNxDUTyvYWSvyw5T_pdYnNHySHUVVmbdfHIc-dCnuMA5W4nbLpQkIYnH0eTH-YCFQywWMR9SoS_m9iueO_Zvjn_C2PwxK7_1OM0MnLjR6LqhkJFpIY-68bDU.rM0o6ytShiE_gbBSqp4TNnfBsuJUcUOJwdTYlyX93-0&dib_tag=se&keywords=V-Slot+20x20x500+Linear+Rail&qid=1767666841&sprefix=v-slot+20x20x500+linear+rail%2Caps%2C157&sr=8-4
WCP-0643 | 250T 5M 9mm Wide Belt | 1 | https://wcproducts.com/products/htd-timing-belts-9mm-width
17HS13-0404S-PG5 | Nema 17 Stepper Motor Bipolar L=34mm w/ Gear Ratio 14:1 Planetary Gearbox | 2 | https://www.amazon.com/gp/product/B00QA8XUGC/ref=ox_sc_act_title_10?smid=AWQBCGWISS7BL&psc=1
6816-2RS-80mm | Ball Bearing 80x100x10mm Sealed | 1 | https://www.amazon.com/gp/product/B07RQ4RXDR/ref=ox_sc_act_title_4?smid=A1THAZDOWP300U&th=1
TSA-26-P-2001 | Cam Shaft Cap | 4 | https://cad.onshape.com/documents/f3370c452f54d75f3c4d6ebc/w/d75891e42061a97cb25fbb77/e/19dbb1aef07b81d3e2e158b9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
TSA-26-P-2002 | Cam Shaft Upper | 4 | https://cad.onshape.com/documents/f3370c452f54d75f3c4d6ebc/w/d75891e42061a97cb25fbb77/e/19dbb1aef07b81d3e2e158b9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
TSA-26-P-2003 | Cam Shaft Lower | 4 | https://cad.onshape.com/documents/f3370c452f54d75f3c4d6ebc/w/d75891e42061a97cb25fbb77/e/19dbb1aef07b81d3e2e158b9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
TSA-26-P-2004 | ThunderHex 0.5 in ID 1.25in OD bearing | 4 | https://wcproducts.com/products/wcp-0778?variant=35666611994784
TSA-26-P-2005 | 12mm ID 18mm OD 4mm thickness bearings | 16 | https://www.amazon.com/gp/product/B082PQ8DC2/ref=ox_sc_act_title_28?smid=A30WUG2ZDGM0XM&psc=1
TSA-26-P-2006 | Output Shaft | 4 | https://cad.onshape.com/documents/f3370c452f54d75f3c4d6ebc/w/d75891e42061a97cb25fbb77/e/19dbb1aef07b81d3e2e158b9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
TSA-26-P-2007 | Backplate | 4 | https://cad.onshape.com/documents/f3370c452f54d75f3c4d6ebc/w/d75891e42061a97cb25fbb77/e/19dbb1aef07b81d3e2e158b9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
TSA-26-P-2008 | M5 * 60mm Hex Socket Head Cap Screw | 36 | https://www.aliexpress.us/item/3256805692722422.html
TSA-26-P-2009 | Housing | 4 | https://cad.onshape.com/documents/f3370c452f54d75f3c4d6ebc/w/d75891e42061a97cb25fbb77/e/19dbb1aef07b81d3e2e158b9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
TSA-26-P-2010 | Cycloidal Disk | 8 | https://cad.onshape.com/documents/f3370c452f54d75f3c4d6ebc/w/d75891e42061a97cb25fbb77/e/19dbb1aef07b81d3e2e158b9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
TSA-26-P-2011 | 5mm ID 9mm OD needle roller bearings | 72 | https://www.aliexpress.us/item/3256804660266970.html?src=google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
TSA-26-P-2012 | Cap Plate | 4 | https://cad.onshape.com/documents/f3370c452f54d75f3c4d6ebc/w/d75891e42061a97cb25fbb77/e/19dbb1aef07b81d3e2e158b9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
TSA-26-P-2013 | Ball Bearings Z2 30mm x 37mm x 4mm | 8 | https://www.aliexpress.us/item/2255800723290638.html?src=google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
TSA-26-P-2014 | 4mm Spacer for M5 | 108 | https://cad.onshape.com/documents/f3370c452f54d75f3c4d6ebc/w/d75891e42061a97cb25fbb77/e/19dbb1aef07b81d3e2e158b9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
TSA-26-P-2015 | 3D-Print Adapter (1/2" Hex Bore, Thrifty Profile) | 4 | https://wcproducts.com/products/wcp-1121?variant=44283598045396
TSA-26-P-2016 | Nema 17 Stepper Motor Bipolar L=34mm w/ Gear Ratio 14:1 Planetary Gearbox | 4 | https://www.amazon.com/gp/product/B00QA8XUGC/ref=ox_sc_act_title_10?smid=AWQBCGWISS7BL&psc=1
TSA-26-P-3001 | Base Arm Segment | 3 | https://cad.onshape.com/documents/f3370c452f54d75f3c4d6ebc/w/d75891e42061a97cb25fbb77/e/19dbb1aef07b81d3e2e158b9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
TSA-26-P-3002 | Arm segment Cap Plate | 4 | https://cad.onshape.com/documents/f3370c452f54d75f3c4d6ebc/w/d75891e42061a97cb25fbb77/e/19dbb1aef07b81d3e2e158b9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
TSA-26-P-3003 | Gripper Mount Arm Segment | 1 | https://cad.onshape.com/documents/f3370c452f54d75f3c4d6ebc/w/d75891e42061a97cb25fbb77/e/19dbb1aef07b81d3e2e158b9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
TSA-26-P-3004 | Turret Mounted Arm Segment | 1 | https://cad.onshape.com/documents/f3370c452f54d75f3c4d6ebc/w/d75891e42061a97cb25fbb77/e/19dbb1aef07b81d3e2e158b9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
TSA-26-P-4001 | Spur Gear 29T Non-Powered | 1 | https://cad.onshape.com/documents/f3370c452f54d75f3c4d6ebc/w/d75891e42061a97cb25fbb77/e/19dbb1aef07b81d3e2e158b9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
TSA-26-P-4002 | Spur Gear 29T - Motor Side | 1 | https://cad.onshape.com/documents/f3370c452f54d75f3c4d6ebc/w/d75891e42061a97cb25fbb77/e/19dbb1aef07b81d3e2e158b9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
TSA-26-P-4003 | Claw Cap Plate | 1 | https://cad.onshape.com/documents/f3370c452f54d75f3c4d6ebc/w/d75891e42061a97cb25fbb77/e/19dbb1aef07b81d3e2e158b9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
TSA-26-P-4004 | Servo Mount | 1 | https://cad.onshape.com/documents/f3370c452f54d75f3c4d6ebc/w/d75891e42061a97cb25fbb77/e/19dbb1aef07b81d3e2e158b9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
TSA-26-P-4005 | Claw Secondary Bar | 2 | https://cad.onshape.com/documents/f3370c452f54d75f3c4d6ebc/w/d75891e42061a97cb25fbb77/e/19dbb1aef07b81d3e2e158b9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
TSA-26-P-4006 | Claw | 2 | https://cad.onshape.com/documents/f3370c452f54d75f3c4d6ebc/w/d75891e42061a97cb25fbb77/e/19dbb1aef07b81d3e2e158b9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
TSA-26-P-4007 | Base | 1 | https://cad.onshape.com/documents/f3370c452f54d75f3c4d6ebc/w/d75891e42061a97cb25fbb77/e/19dbb1aef07b81d3e2e158b9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
TSA-26-P-4008 | ArduCAM Snap-In Insert | 1 | https://cad.onshape.com/documents/f3370c452f54d75f3c4d6ebc/w/d75891e42061a97cb25fbb77/e/19dbb1aef07b81d3e2e158b9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
TSA-26-P-4009 | Distance Sensor - VL53L0X v8 | 1 | https://www.aliexpress.us/item/3256807932833735.html?src=google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
TSA-26-P-4010 | ArduCAM - IMX477 | 1 | amazon.com/gp/product/B09VSVB4DT/ref=ox_sc_act_title_6?smid=A2IAB2RW3LLT8D&psc=1
TSA-26-P-4011 | Servo - DSSERVO 30KG | 2 | https://www.aliexpress.us/item/3256807345822029.html?src=google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

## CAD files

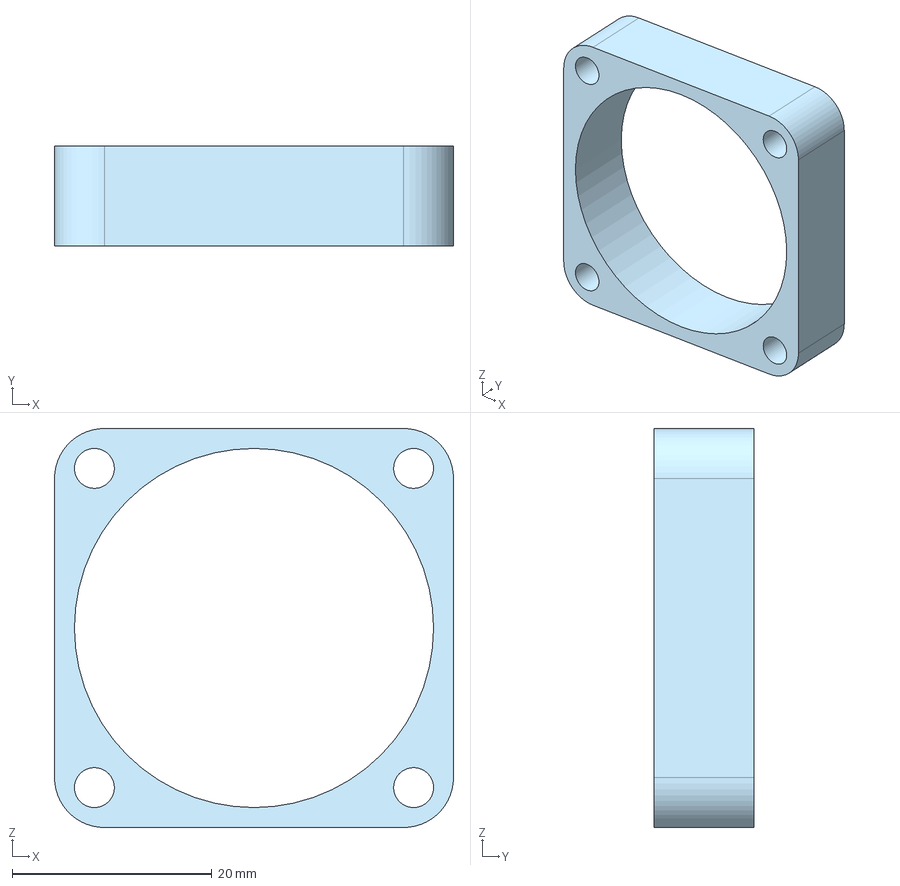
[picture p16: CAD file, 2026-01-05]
cad/Electronics/Noctua NF-A4x10 FLX placeholder.step
40.0 x 10.0 x 40.0 mm

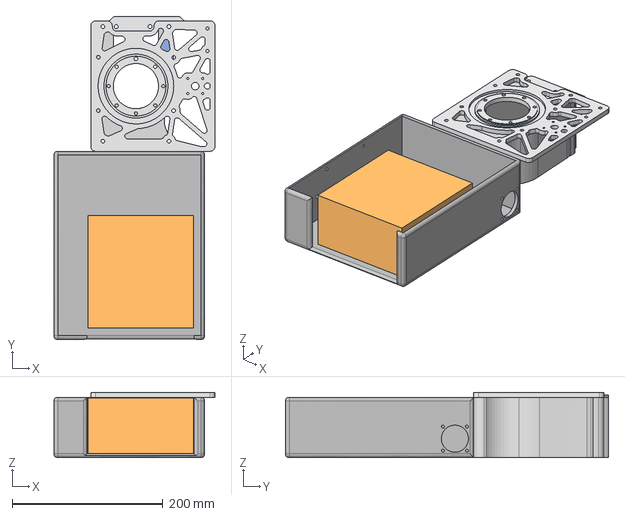
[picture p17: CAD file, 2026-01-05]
cad/Gantry + turret/Turret Subplate.step
213.8 x 429.0 x 86.4 mm

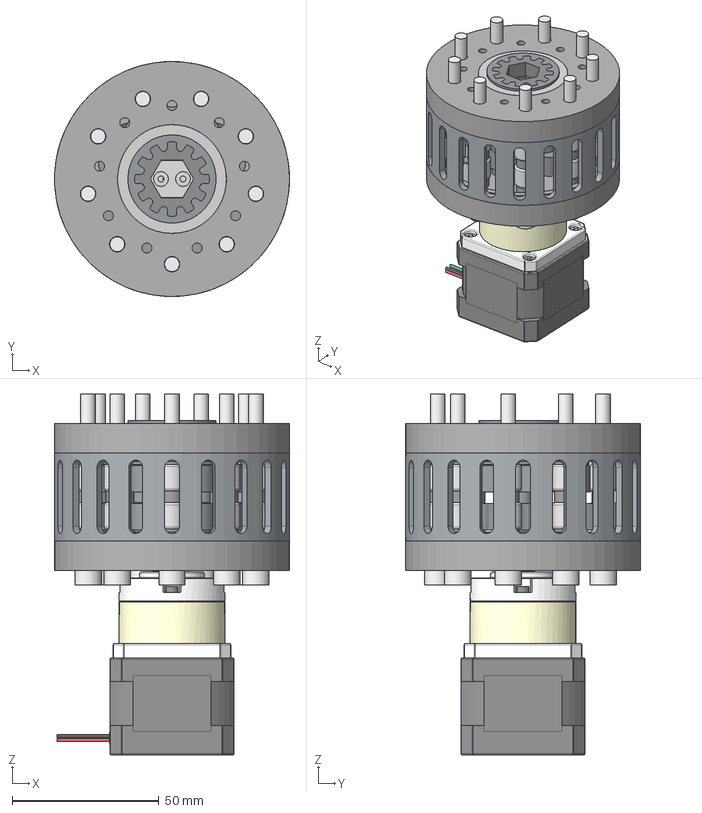
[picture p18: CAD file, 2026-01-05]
cad/NEMA 17 Cycloidal Drive/NEMA 17 + Drive (1).step
80.0 x 80.0 x 122.9 mm
17HS13-0404S-PG5
4mm spacer for M5 bolt x 27
Cycloid Outer Bearing 9mm OD x 18
Placeholder for 12mm ID 18mm OD 4mm thickness bearings x 4
long M5 placeholder x 9
ThunderHex 0.5 in ID 1.25in OD bearing
30mm ID 37mm OD 4mm Thickness Bearing x 2
CAM TOP
Cycloidal disk 2.0 x 2
CAM CAP
Housing
Nema 17 mounting & backplate
Output Shaft
CAM
3D-Print Adapter (1/2" Hex Bore, Thrifty Profile)
Cap plate

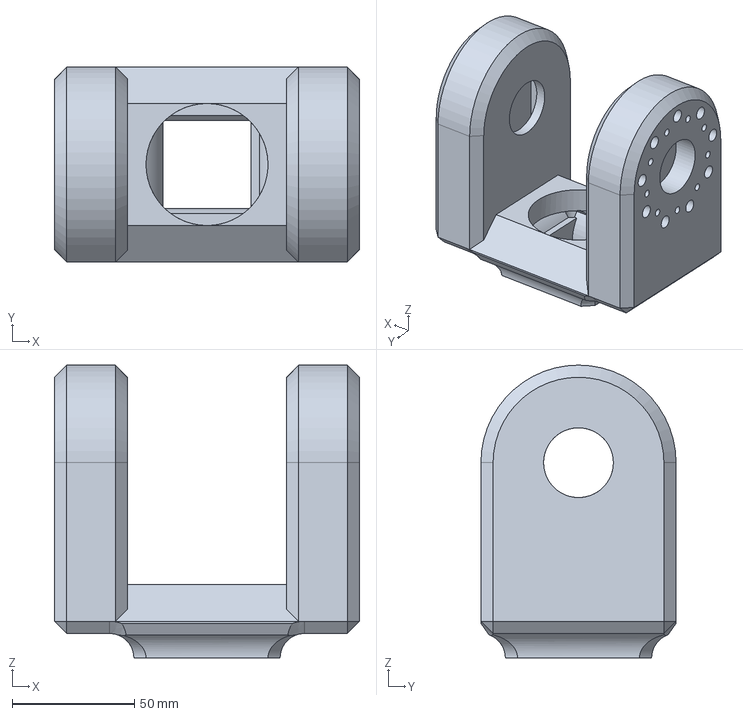
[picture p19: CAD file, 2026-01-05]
cad/Robotic Arm/ARM SEGMENTS/TSA-25-P-2300.step
125.0 x 80.0 x 120.0 mm

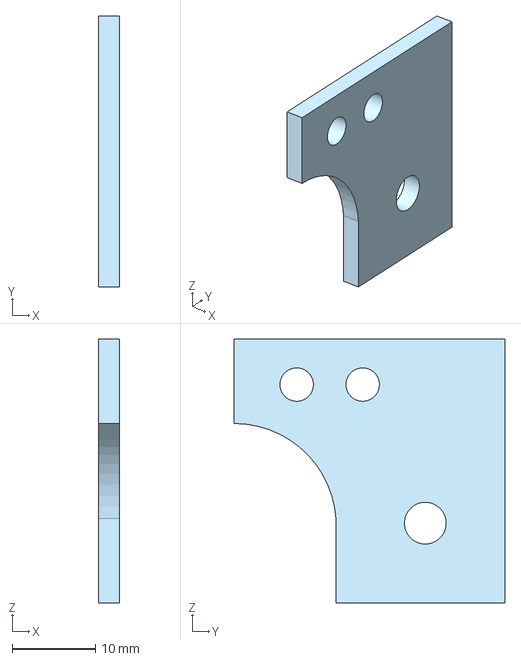
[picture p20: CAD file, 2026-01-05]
cad/Robotic Arm/Gripper/CLAW CLIP.step
2.54 x 32.6 x 31.8 mm

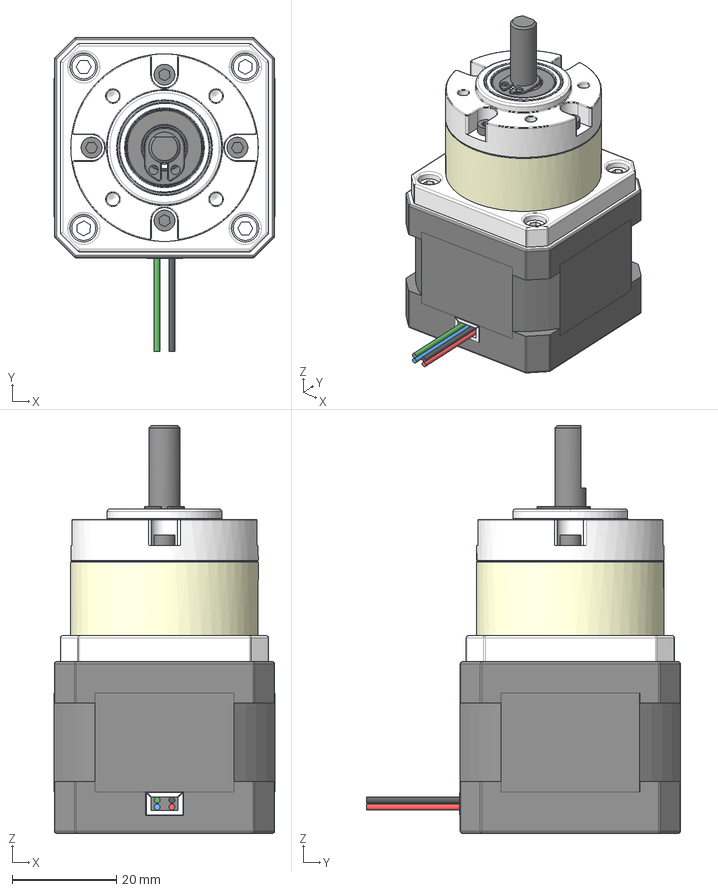
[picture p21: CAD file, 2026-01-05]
cad/Robotic Arm/NEMA 17 Stepper Motor.step
42.3 x 60.3 x 78.3 mm

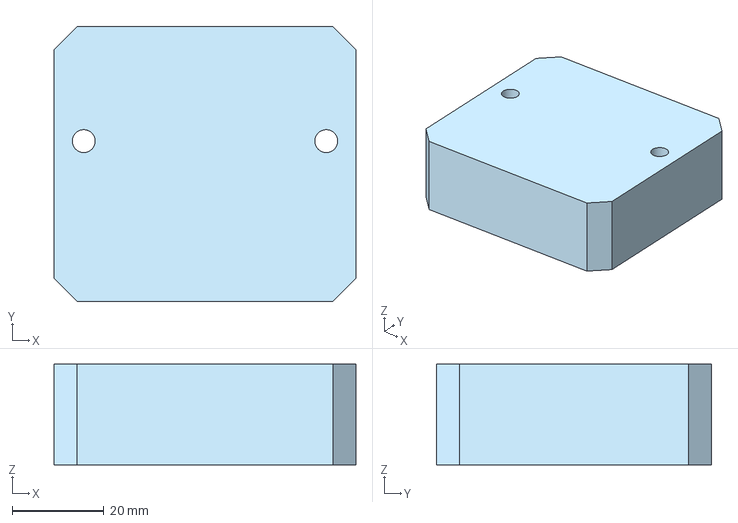
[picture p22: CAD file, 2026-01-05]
cad/Electronics/12V to 9V buck converter placeholder.step
66.0 x 60.0 x 22.0 mm

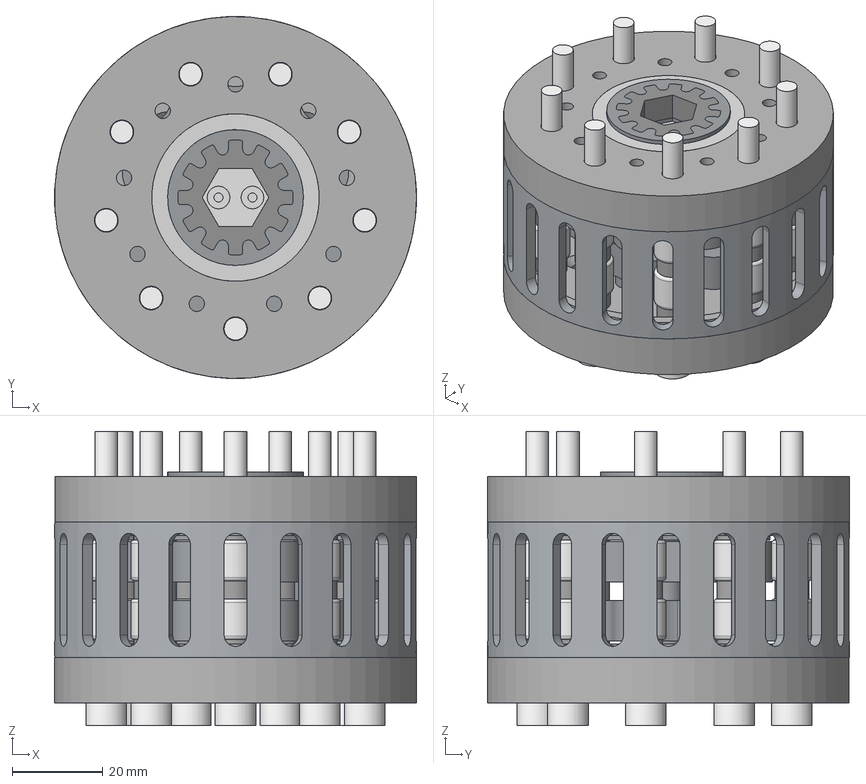
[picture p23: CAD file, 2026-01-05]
cad/NEMA 17 Cycloidal Drive/Cycloidal Drive NEMA 17 (1).step
80.0 x 80.0 x 65.0 mm
4mm spacer for M5 bolt x 27
Cycloid Outer Bearing 9mm OD x 18
30mm ID 37mm OD 4mm Thickness Bearing x 2
Placeholder for 12mm ID 18mm OD 4mm thickness bearings x 4
Cycloidal disk 2.0 x 2
Nema 17 mounting & backplate
Output Shaft
long M5 placeholder x 9
CAM
ThunderHex 0.5 in ID 1.25in OD bearing
Cap plate
3D-Print Adapter (1/2" Hex Bore, Thrifty Profile)
Housing
CAM TOP
CAM CAP

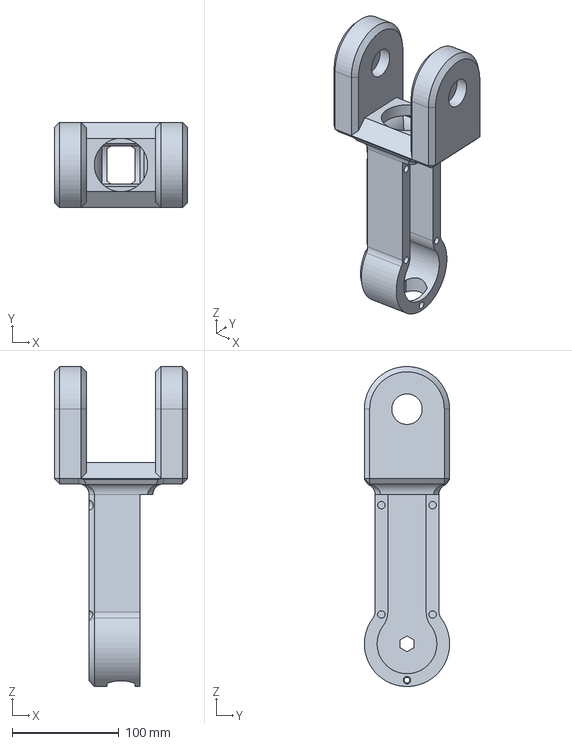
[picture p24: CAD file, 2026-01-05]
cad/Robotic Arm/ARM SEGMENTS/TSA-25-P-2200.step
125.0 x 80.0 x 300.0 mm

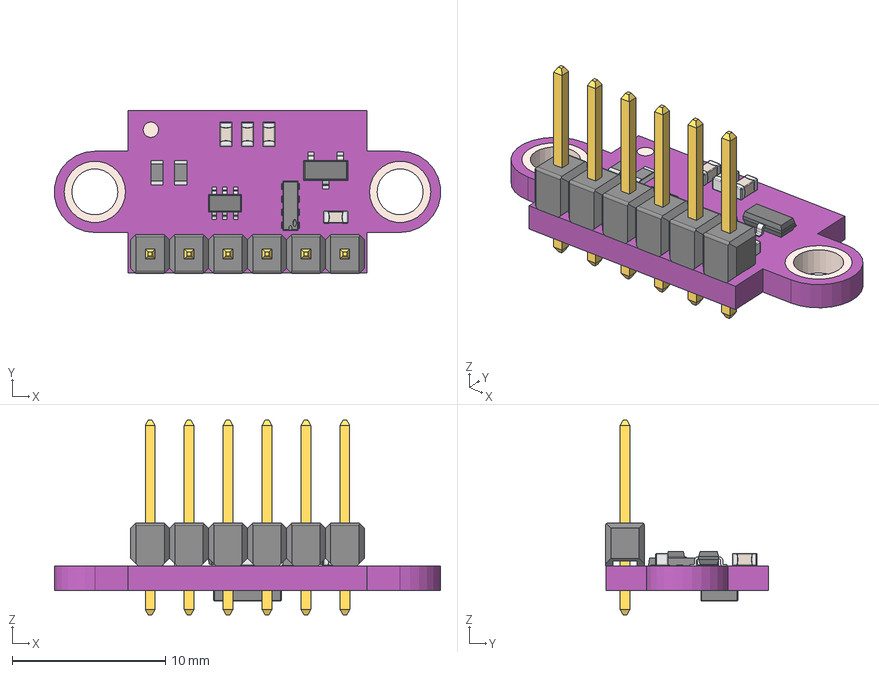
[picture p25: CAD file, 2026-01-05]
cad/Robotic Arm/Gripper/VL53L0X v8.step
25.2 x 10.6 x 12.7 mm
1x6 TH Pitch 2.54mm v1 x 12
VL53L0X x 43
RES0603 v1 (1) x 4
SOT-23-6 v2
RES0603 v1 x 4
CeramicBody (3)
Pin2 (3)
Pin1 (3)
Pin1 (1)
Pin2 (1)
CeramicBody (1)
Pin2
Pin1
CeramicBody
CeramicBody (2)
Pin2 (2)
Pin1 (2)
SOT-23-3 v1
pcb x 2
pads x 12
top
kork
DIP-8 N v1

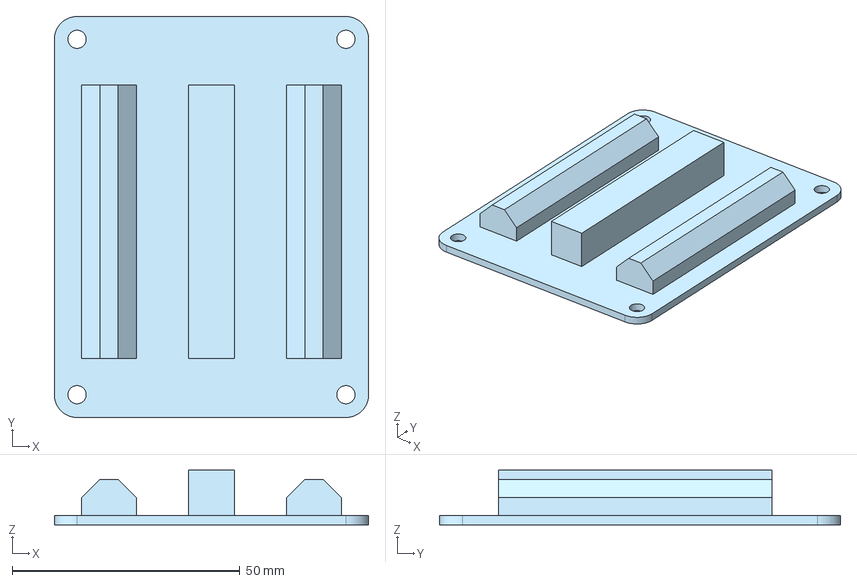
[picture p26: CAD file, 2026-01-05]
cad/Electronics/DC Breakout board placeholder.step
69.0 x 88.0 x 12.0 mm

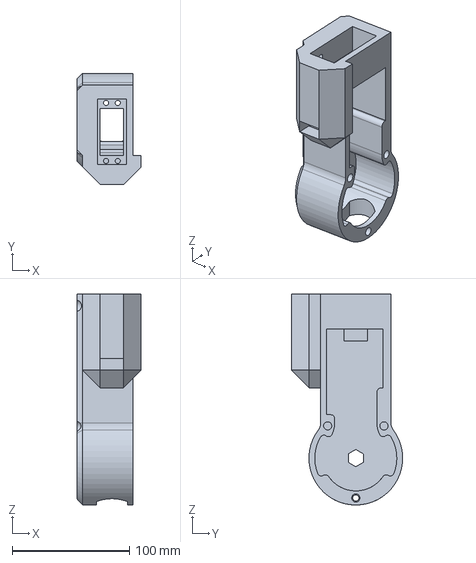
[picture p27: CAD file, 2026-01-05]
cad/Robotic Arm/ARM SEGMENTS/TSA-25-P-2400.step
55.0 x 95.0 x 180.0 mm

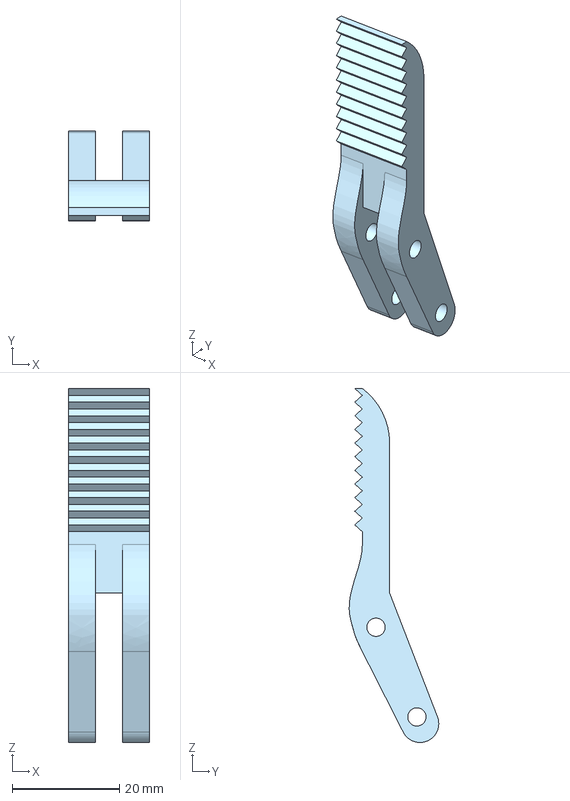
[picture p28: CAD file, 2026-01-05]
cad/Robotic Arm/Gripper/Claws.step
15.0 x 16.7 x 65.9 mm

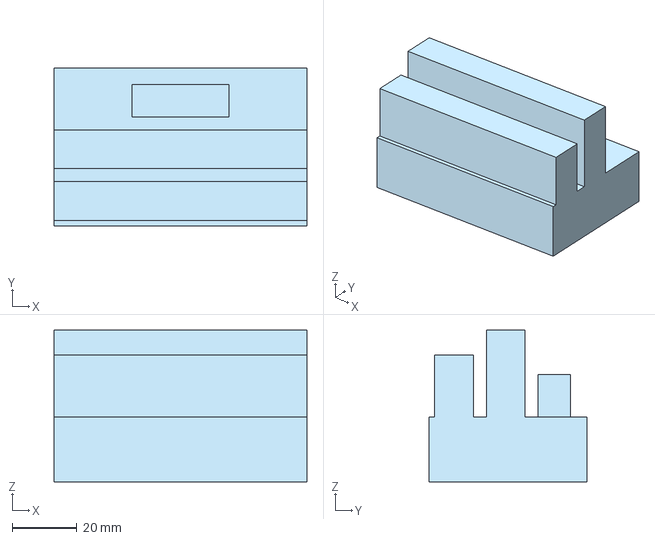
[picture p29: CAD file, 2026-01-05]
cad/Electronics/25A Power Distribution Placeholder.step
78.0 x 48.6 x 46.8 mm

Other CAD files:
cad/Final Robotic Assistant Assembly.step
cad/Robotic Arm/ARM SEGMENTS/TSA-25-P-2100.step
cad/Robotic Arm/Gripper/ClawSideBAR.step
cad/Electronics/ArduinoMega_STEP_AP203 (1).step
cad/Robotic Arm/ARM SEGMENTS/Base Arm Segment 1.0 (1).step
cad/Robotic Arm/Gripper/Base2.step
cad/Robotic Arm/Gripper/IMX477 (12.3MP)_TOP.step
cad/Robotic Arm/Gripper/Motor model (1).step
cad/Robotic Arm/Gripper/MotorMount.step
cad/Robotic Arm/Gripper/Spur Gear 29T - Motor side.step
cad/Robotic Arm/Gripper/Spur Gear 29T.step

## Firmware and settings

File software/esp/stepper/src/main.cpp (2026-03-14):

#include <Arduino.h>
#include <driver/twai.h>
#include <esp_task_wdt.h>

#define MY_MOTOR_ID  0x100
#define BROADCAST_ID 0x1FF

#define STEP_PIN 26
#define DIR_PIN  27
#define EN_PIN   25

#define MOTOR_STEPS 200
#define GEAR_RATIO  112
#define MICROSTEPS  16

int step_delay = 60;
bool can_ready = false;

void setup() {
  Serial.begin(115200);
  delay(2000); // Give serial time to connect

  // Disable watchdog so CAN init doesn't get killed
  esp_task_wdt_deinit();

  // Motor setup
  pinMode(STEP_PIN, OUTPUT);
  pinMode(DIR_PIN,  OUTPUT);
  pinMode(EN_PIN,   OUTPUT);
  digitalWrite(EN_PIN, LOW);
  digitalWrite(DIR_PIN, HIGH);

  // CAN setup
  twai_general_config_t g_config = TWAI_GENERAL_CONFIG_DEFAULT(GPIO_NUM_4, GPIO_NUM_22, TWAI_MODE_NORMAL);
  twai_timing_config_t  t_config = TWAI_TIMING_CONFIG_500KBITS();
  twai_filter_config_t  f_config = TWAI_FILTER_CONFIG_ACCEPT_ALL();

  if (twai_driver_install(&g_config, &t_config, &f_config) != ESP_OK) {
    Serial.println("TWAI install FAILED - running without CAN");
    return; // Don't while(1) - let loop() run safely
  }

  if (twai_start() != ESP_OK) {
    Serial.println("TWAI start FAILED - running without CAN");
    return;
  }

  can_ready = true;
  Serial.printf("Motor Node Ready - ID: 0x%03X\n", MY_MOTOR_ID);
}

void step_motor(long steps) {
  for (long i = 0; i < steps; i++) {
    digitalWrite(STEP_PIN, HIGH);
    delayMicroseconds(step_delay);
    digitalWrite(STEP_PIN, LOW);
    delayMicroseconds(step_delay);
  }
}

void loop() {
  if (!can_ready) {
    Serial.println("CAN not ready - waiting...");
    delay(2000);
    return;
  }

  twai_message_t msg;
  if (twai_receive(&msg, 0) == ESP_OK) { // Non-blocking
    if (msg.data_length_code >= 5 &&
       (msg.identifier == MY_MOTOR_ID || msg.identifier == BROADCAST_ID)) {

      long steps = msg.data[0]
                 | ((long)msg.data[1] << 8)
                 | ((long)msg.data[2] << 16)
                 | ((long)msg.data[3] << 24);

      byte direction = msg.data[4];

      Serial.printf("CMD: %ld steps, dir=%d\n", steps, direction);
      digitalWrite(DIR_PIN, direction == 0 ? HIGH : LOW);
      step_motor(steps);
      Serial.println("Done");
    }
  }

  delay(1); // Yield to system tasks
}

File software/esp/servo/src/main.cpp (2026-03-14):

#include <Arduino.h>
#include <driver/twai.h>

void setup() {
  Serial.begin(115200);
  delay(2000);
  
  Serial.println("Starting CAN receiver...");

  twai_general_config_t g_config = TWAI_GENERAL_CONFIG_DEFAULT(GPIO_NUM_4, GPIO_NUM_16, TWAI_MODE_NORMAL);
  twai_timing_config_t  t_config = TWAI_TIMING_CONFIG_500KBITS();
  twai_filter_config_t  f_config = TWAI_FILTER_CONFIG_ACCEPT_ALL();

  if (twai_driver_install(&g_config, &t_config, &f_config) != ESP_OK) {
    Serial.println("TWAI install FAILED");
    while(1);
  }

  if (twai_start() != ESP_OK) {
    Serial.println("TWAI start FAILED");
    while(1);
  }

  Serial.println("CAN Ready - Waiting for messages...");
}

void loop() {
  twai_message_t msg;
  
  esp_err_t result = twai_receive(&msg, pdMS_TO_TICKS(1000));
  
  if (result == ESP_OK) {
    Serial.print("Received ID 0x");
    Serial.print(msg.identifier, HEX);
    Serial.print(": ");
    for (int i = 0; i < msg.data_length_code; i++) {
      Serial.print(msg.data[i], HEX);
      Serial.print(" ");
    }
    Serial.println();
  } else if (result == ESP_ERR_TIMEOUT) {
    // Print status every timeout
    twai_status_info_t status;
    twai_get_status_info(&status);
    Serial.print("Waiting... state:");
    Serial.print(status.state);
    Serial.print(" tx_err:");
    Serial.print(status.tx_error_counter);
    Serial.print(" rx_err:");
    Serial.println(status.rx_error_counter);
  } else {
    Serial.print("Receive error: ");
    Serial.println(result);
  }
}

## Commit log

2026-01-05 cad readme
2026-01-05 sample csv
    [BOM.csv]
2026-01-05 script working
    [BOM.csv]
2026-01-05 test in csv
    [BOM.csv]
2026-01-05 docs: auto-update BOM table in README
2026-01-05 Enhance README with project motivation details
    Expanded the 'Why we Made This' section to explain the motivation behind the robotic arm project, emphasizing accessibility, cost reduction, and open-source principles.
2026-01-05 Refactor project description for clarity and conciseness
    Removed redundant text and improved readability of the section explaining the purpose and goals of the robotic arm project.
2026-01-05 Update BOM entry for motor driver in README
2026-01-05 Enhance README with detailed project description
    Added detailed description of the robotic arm's features, benefits, and intended use in educational and lab environments, emphasizing its accessibility and open-source nature.
2026-01-05 Rename Screenshot 2025-12-30 204946.png to Gantry
2026-01-05 Rename Screenshot 2025-12-30 205156.png to Full Arm Assembly
2026-01-05 Rename Screenshot 2025-12-30 205338.png to Turret+arm
2026-01-06 Add files via upload
    Added Updated BOM 1/6/26
    [TSA-26-0000 Bill Of Materials.csv]
2026-01-06 updated bom
    [BOM.csv]
2026-01-07 removed sample csv
    [TSA-26-0000 Bill Of Materials.csv]
2026-01-07 Rename Robotic Arm + Gantry Final.step to Final Robotic Assistant Assembly
2026-01-07 Update and rename Final Robotic Assistant Assembly to Final Robotic Assistant Assembly.step
    [Final Robotic Assistant Assembly.step]
2026-01-07 Fix image paths in README and add turret arm render
    Corrected image paths and added a new render.
2026-01-07 Rename Turret+arm to StationaryArm
2026-01-07 Add 3D CAD Model section to README
    Added a new section for the 3D CAD model with an image.
2026-01-07 Rename section from '3D CAD Model' to 'Wiring Diagram'
2026-01-08 Add M2 x 25mm Cap Screws to BOM
    [BOM.csv]
2026-01-14 Modify BOM.csv with updated quantities and new item
    Updated quantities for Cycloidal Disk and added a new entry for Cycloidal Disk out of phase.
    [BOM.csv]
2026-01-21 Revise introduction for clarity and flow
